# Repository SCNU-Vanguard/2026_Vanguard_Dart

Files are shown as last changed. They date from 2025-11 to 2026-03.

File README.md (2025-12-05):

# 2026 Vanguard Dart Project

## 项目简介 / Project Overview

本仓库为华南师范大学 Vanguard 战队 2026 赛季飞镖系统的综合仓库，包含 STM32 控制系统、视觉处理系统、飞镖系统机械结构和上位机图形化界面。

This repository contains the comprehensive codebase for SCNU Vanguard's 2026 season Dart system, including STM32 control system, vision processing system, dart's structure and upper computer GUI.

## 项目结构 / Project Structure

```
2026_Vanguard_Dart/
├── 2026_Vanguard_Dart_STM32_Ctrl/    # STM32控制系统 (C/C++)
│   ├── Dart_Ctrl/                     # STM32主控代码（A板）
│   └── 相关手册/                      # 相关技术文档
│
├── 2026_Vanguard_Dart_JestonPart/    # Jetson视觉处理系统 (Python/C++)
│   └── README.md                      # 视觉系统文档
│
└── 2026_Vanguard_Dart_UPC_Code/      # 上位机图形化界面 (Python)
|   ├── SourceCode/                    # 源代码
|   ├── docs/                          # 文档
|   ├── tests/                         # 测试代码
└── 2026_Vangaurd_Dart_Structure
    └──飞镖(V2improved)                #飞镖系统机械机构
```

## 功能模块 / Function Modules

### 1. STM32 控制系统 (STM32 Control System)

- **平台**: STM32F427xx（A 板）
- **开发环境**: Keil MDK-ARM
- **功能**:
  - 飞镖发射控制
  - CAN 总线通信
  - 电机控制 (大疆/达妙电机)
  - UART 通信
  - FreeRTOS 实时操作系统

### 2. 视觉处理系统 (Vision Processing System)

- **平台**: NVIDIA Jetson
- **功能**:
  - 目标识别与追踪
  - 图像处理
  - 视觉算法

### 3. 上位机系统 (Upper Computer System)

- **语言**: Python
- **功能**:
  - 实时数据监控
  - 参数调试界面
  - 数据可视化
  - UART 串口通信

## 开发环境 / Development Environment

### STM32 开发

- **IDE**: Keil MDK-ARM / STM32CubeIDE
- **调试器**: ST-Link
- **工具链**: ARM GCC

### 视觉处理

- **系统**: Ubuntu (Jetson)
- **语言**: Python 3.x / C++
- **依赖**: OpenCV, NumPy 等

### 上位机开发

- **语言**: Python 3.x
- **主要库**: PyQt5/PySide, pyserial, matplotlib 等
- **详见**: `2026_Vanguard_Dart_UPC_Code/requirements.txt`

## 快速开始 / Quick Start

### STM32 部分

```bash
cd 2026_Vanguard_Dart_STM32_Ctrl/Dart_Ctrl
# 使用Keil打开 Dart_Ctrl.uvprojx 工程文件
```

### 视觉处理部分

```bash
cd 2026_Vanguard_Dart_JestonPart
# 查看README.md了解详细说明
```

### 上位机部分

```bash
cd 2026_Vanguard_Dart_UPC_Code
# 安装依赖
pip install -r requirements.txt
# 运行主程序
python SourceCode/main_app.py
```

## 技术栈 / Tech Stack

- **嵌入式**: C/C++, FreeRTOS, STM32 HAL
- **视觉**: Python/C++, OpenCV
- **上位机**: Python, PyQt5, Matplotlib
- **通信**: UART, CAN
- **版本控制**: Git

## 贡献指南 / Contributing

1. Fork 本仓库
2. 创建特性分支 (`git checkout -b feature/AmazingFeature`)
3. 提交更改 (`git commit -m 'Add some AmazingFeature'`)
4. 推送到分支 (`git push origin feature/AmazingFeature`)
5. 提交 Pull Request

## 团队 / Team

华南师范大学 Vanguard 战队  
SCNU Vanguard Team

## 许可证 / License

本项目仅供华南师范大学 Vanguard 战队内部学习和比赛使用。

This project is for internal learning and competition use of SCNU Vanguard Team only.

---

_Last Updated: 2025 年 12 月_

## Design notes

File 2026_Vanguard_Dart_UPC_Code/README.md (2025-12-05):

# 上位机助手 (Host Computer Assistant)

**版本 v1.0.01 - UI 美化增强版**

---

## 📝 项目简介

本项目是一个基于 **Ubuntu 22.04** 和 **PyQt5** 开发的上位机助手，使用 **Python 3.10+**。专注于 **UART 串口通信**，支持 USB 虚拟串口和实体硬件串口（如 Jetson Nano 的/dev/ttyTHS1），用于与下位机（如 STM32、Arduino 等）进行通信、实时调节 PID 参数、多通道波形显示。

本项目原为华南师范大学 Vanguard 战队飞镖机器人上位机研发项目。

---

## ✨ 特性

### 核心功能

- **现代 UI 设计**: 采用黑色背景与粉色点缀的时尚界面风格
- **专注 UART 通信**: 精简的 UART 串口通信方案
  - 支持 USB 转 UART 虚拟串口（/dev/ttyUSB0, /dev/ttyACM0 等）
  - 支持实体 UART 硬件串口（Jetson Nano: /dev/ttyTHS1, Raspberry Pi: /dev/ttyAMA0 等）
  - **自动串口扫描和刷新** - 无需手动输入
- **模块化设计**: 通信功能封装在独立模块中，易于维护和扩展
- **实时 PID 调节**: 提供专门界面用于动态调整下位机的 PID 参数
- **手动控制**: 支持手动指令发送和 Hex 格式

### 🆕 v1.0.01 功能

- **智能日志系统**

  - 自动时间戳标记
  - 颜色分类显示（错误/成功/发送/接收）
  - 自动滚动到最新消息

- **多通道实时波形显示**

  - 支持同时显示多条曲线
  - 8 种预设颜色自动区分
  - 实时图例显示
  - 暂停/继续绘图控制
  - 自动缩放功能
  - 数据缓冲管理（默认 1000 点）

- **状态栏信息**

  - 实时连接状态显示
  - 数据接收统计
  - 绘图点数和通道数统计

- **配置持久化**

  - 自动保存上次使用的串口和波特率
  - 下次启动自动加载配置

- **数据导出**: 支持多通道波形数据导出为 CSV 格式

- **字体全面加粗**

  - 全局字体权重提升至 600 (Semi-Bold)
  - 所有文字更清晰醒目
  - 特别优化低 DPI 显示器显示效果

- **圆角美化**

  - 所有组件圆角增大 30-67%
  - 分组框: 10px → 15px
  - 输入框/按钮: 5px → 8px
  - 标签页: 8px → 10px
  - 主窗口: 0px → 12px

- **边框增强**

  - 所有边框加粗至 2px (原来 1px)
  - 组件边界更清晰
  - 视觉层次更分明

- **内边距优化**

  - 所有组件内边距增加 20-50%
  - 界面更宽松，呼吸感更好
  - 分组框增加 15px padding

- **新增样式**

  - 工具按钮圆角和悬停效果
  - 分组框标题增加背景和圆角
  - 复选框尺寸增大 20%
  - 滚动条加粗更易拖动

- **代码规范**: 遵循 PEP8 代码规范，确保代码高质量和可读性

---

## 🛠️ 环境要求

### 系统要求

- **操作系统**: Ubuntu 22.04 LTS（推荐）或其他 Linux 发行版
- **Python 版本**: Python 3.10 或更高
- **硬件**: 支持 USB 串口或板载硬件串口（如 Jetson Nano）

### 依赖包

- PyQt5 >= 5.15.0
- pyserial >= 3.5

---

## 📦 安装方法

### 方法一：使用 Miniconda 虚拟环境（推荐）

#### 1. 安装 Miniconda

如果还没有安装 Miniconda，请先安装：

```bash
# 下载Miniconda安装脚本
wget https://repo.anaconda.com/miniconda/Miniconda3-latest-Linux-x86_64.sh

# 运行安装脚本
bash Miniconda3-latest-Linux-x86_64.sh

# 按照提示完成安装，重启终端使其生效
```

#### 2. 创建并激活虚拟环境

```bash
# 创建名为uart_host的Python 3.10环境
conda create -n uart_host python=3.10 -y

# 激活环境
conda activate uart_host
```

#### 3. 安装依赖

```bash
# 进入项目目录
cd /path/to/LinuxUPC

# 安装系统依赖（仅首次需要）
sudo apt update
sudo apt install -y build-essential

# 使用Conda安装PyQt5
conda install -y pyqt

# 安装其他Python依赖
pip install -r requirements.txt
```

#### 4. 配置串口权限

```bash
# 将当前用户添加到dialout组（仅首次需要）
sudo usermod -a -G dialout $USER

# ⚠️ 需要重新登录或重启才能生效
```

#### 5. 运行程序

```bash
# 确保在uart_host环境中
conda activate uart_host

# 运行主程序
python SourceCode/main_app.py
```

---

### 方法二：系统级安装

#### 1. 更新系统包

```bash
sudo apt update && sudo apt upgrade -y
```

#### 2. 安装 Python 和系统依赖

```bash
# 确认Python版本
python3 --version

# 安装依赖
sudo apt install -y python3 python3-pip build-essential
sudo apt install -y python3-pyqt5 python3-pyqt5.qtsvg
```

#### 3. 安装 Python 包

```bash
pip3 install -r requirements.txt
```

#### 4. 配置串口权限

```bash
sudo usermod -a -G dialout $USER
# ⚠️ 需要重新登录或重启
```

#### 5. 运行程序

```bash
python3 SourceCode/main_app.py
```

---

### 方法三：使用自动化脚本

```bash
# 赋予执行权限
chmod +x setup_environment.sh

# 运行配置脚本（自动检测Conda环境）
./setup_environment.sh
```

---

## 🚀 快速开始

### 1. 识别串口设备

```bash
# 列出所有串口设备
ls /dev/tty*

# 查看USB串口（插拔USB观察变化）
ls /dev/ttyUSB*
ls /dev/ttyACM*

# Jetson Nano硬件串口
ls /dev/ttyTHS*
```

### 2. 测试串口连接

```bash
# 查看串口权限
ls -l /dev/ttyUSB0

# 应该看到类似：crw-rw---- 1 root dialout ...
# 确保你的用户在dialout组中
groups
```

### 3. 启动程序

```bash
# 使用Conda环境
conda activate uart_host
python SourceCode/main_app.py

# 或系统Python
python3 SourceCode/main_app.py
```

### 4. 连接设备

1. 在"UART 通信设置"区域输入串口端口（或使用快速选择按钮）
2. 选择波特率（默认 115200）
3. 点击"连接"按钮
4. 在日志区域查看连接状态

---

## 📂 项目结构

```
LinuxUPC/
├── SourceCode/
│   ├── main_app.py              # 主程序入口
│   └── communication/           # 通信模块
│       ├── __init__.py          # 模块初始化
│       └── uart_comm.py         # UART通信实现
├── Weekly/                      # 开发周报
├── requirements.txt             # Python依赖列表
├── setup_environment.sh         # 自动配置脚本
├── README.md                    # 本文件
└── LICENSE                      # 开源协议
```

---

## 🔧 通信协议

### PID 参数发送格式

```
PID,<Kp>,<Ki>,<Kd>
示例: PID,1.0000,0.1000,0.0100
```

### 手动控制指令格式

```
<COMMAND>,<PARAM1>,<PARAM2>,...
示例: MOTOR,1,255
```

### 绘图数据接收格式

```
AT+DRAW+<数据名称>+<数值>
示例:
  AT+DRAW+Temperature+25.5
  AT+DRAW+Voltage+3.3
  AT+DRAW+Humidity+65.2
```

详细绘图功能说明请参考：[docs/绘图功能说明.md](docs/绘图功能说明.md)

---

## 🎨 UI 优化

### 1. 串口管理

- 🔄 **自动扫描**: 启动时自动检测可用串口
- 🔍 **智能显示**: 显示串口设备名称和描述
- ⚡ **快速选择**: USB0/THS1/ACM0 快捷按钮

### 2. 日志增强

- ⏰ **时间戳**: 每条日志自动添加时间（HH:MM:SS 格式）
- 🎨 **颜色编码**:
  - 🔴 红色：错误和失败
  - 🟢 绿色：成功和连接
  - 🔵 蓝色：绘图数据
  - 🟡 黄色：发送命令
  - ⚪ 灰色：一般信息

### 3. 波形控制

- ⏸/▶ **暂停/继续**: 暂停数据绘制但保持接收
- 📐 **自动缩放**: 一键调整视图适应所有数据
- 🗑 **清空波形**: 清除所有曲线和数据
- 💾 **导出数据**: CSV 格式导出所有通道

### 4. 状态栏

- 📊 **实时统计**:
  - 连接状态和串口信息
  - 接收数据包总数
  - 绘图点总数
  - 活动通道数量

---

## 🎯 常见问题

### 1. 串口权限问题

**错误**: `Permission denied: '/dev/ttyUSB0'`

**解决**:

```bash
sudo usermod -a -G dialout $USER
# 重新登录或重启
```

### 2. 串口被占用

**错误**: `Serial port is already open`

**解决**:

```bash
# 查找占用进程
lsof /dev/ttyUSB0

# 结束占用进程
kill -9 <PID>
```

### 3. Jetson Nano 串口配置

对于 Jetson Nano 的硬件串口/dev/ttyTHS1，需要禁用控制台：

```bash
# 禁用串口控制台
sudo systemctl stop nvgetty
sudo systemctl disable nvgetty
```

### 4. PyQt5 安装问题

如果使用 pip 安装 PyQt5 失败，建议：

**Conda 环境**:

```bash
conda install -y pyqt
```

**系统环境**:

```bash
sudo apt install python3-pyqt5
```

---

## 🤝 贡献

欢迎提交 Issue 和 Pull Request！

---

## 📄 开源协议

本项目采用 MIT License，详见 [LICENSE](LICENSE) 文件。

---

## 👨‍💻 作者

**BaleDeng** - 华南师范大学 Vanguard 战队

项目开发日期: 2025-09

当前版本: v1.0.01

---

## 📋 更新日志

### v1.0.00 (2025-09-20) -> v1.0/01 (2025-11-18) - UART 专版

- 🎨 全局字体加粗至 600 (Semi-Bold)
- 🎨 所有圆角增大 30-67%
- 🎨 所有边框加粗至 2px
- 🎨 所有内边距增加 20-50%
- 🎨 新增工具按钮样式
- 🎨 分组框标题增加背景和圆角
- 🎨 复选框尺寸增大 20%
- 🎨 滚动条加粗更易拖动
- 📝 新增 UI 美化对比文档

- ✨ 新增自动串口扫描和刷新功能
- ✨ 新增带时间戳和颜色的智能日志系统
- ✨ 新增实时状态栏和统计信息
- ✨ 新增配置文件自动保存/加载
- ✨ 新增多通道波形显示功能
- ✨ 新增绘图暂停/继续控制
- ✨ 新增自动缩放功能
- 🎨 优化 UI 布局和窗口大小
- 🐛 修复断开连接时的潜在 bug
- 📝 完善文档和测试工具

- 🎉 初始版本发布
- ✨ UART 串口通信基础功能
- ✨ PID 参数调节
- ✨ 手动控制指令发送

---

## 📮 联系方式

如有问题或建议，请通过 GitHub Issues 联系。

---

# 飞镖上位机技术展望与开发方案

## 项目背景

基于当前战队采用拉簧式发射结构+无控飞镖，上位机与视觉暂未合体情况下，参考下面的开源工程以及报告总结。

目标功能：
- 具备场上参数修正功能
- 使用基于树莓派 5/香橙派 5Plus/Jetson Nano 等的可视化 GUI 进行调节 PID 等参数（测试情况下）
- 模拟比赛调节参数过程（梯度飞镖）
- 使用多次校准，从而确定随机固定靶的位置

---

## 飞镖相关开源项目参考

### 西北工业大学报告 (WMJ)

**链接**: <https://bbs.robomaster.com/article/809863?source=4>

**硬件部分**:
- 采用树莓派 Zero2W 平台
- 运行 RaspberryOS
- 使用 OpenCV 进行图像识别和处理
- 通过 CSI 相机数据流识别引导灯
- 串口通信基于 wiringpi 库，使用 CRC16 校验

**下位机**:
- STM32 使用 HAL 库裸机开发
- 板载 BMI088 + IST8310
- 采用 Mahony 算法进行四元数解算融合九轴 IMU

**镖架上位机**:
- 基于 Intel NUC10 平台（Ubuntu 20.04）
- 使用 OpenCV + GalaxyAPI（大恒工业相机）
- CAN 通信

---

### 四川大学 火锅战队 - 全站仪上位机开源

**链接**: 
- <https://bbs.robomaster.com/article/803749?source=4>
- <https://github.com/KangweiYang/dartRack_upper>

**技术方案**:
- 使用全站仪
- 软件以 Qt (C++) 为基础
- 集成串口界面进行标定数据通信
- 通过串口调节界面调节参数

---

### 西安交通大学 笃行战队

**链接**: <https://bbs.robomaster.com/article/803714?source=4>

**特点**:
- 基于皮筋发射系统
- 未开源上位机实现方案

---

### 西南大学 GKD 战队 (RM2021)

**链接**: 
- <https://bbs.robomaster.com/article/8355>
- <https://gitee.com/gong-yuzhi/rmfashejia> - 发射架结构
- <https://gitee.com/rogue_shadowdancer/gkdfeibiao> - 飞镖结构

**技术方案**:
- 皮筋发射结构
- 使用 nRF24L01 模块作为远程调参接收的载体
- 上位机采用 PyQt5 设计
- 理论最远 10 米进行调参
- 使用第三方串口软件（类似 VOFA、SerialPlot）进行可视化监控
- 支持波形导出为 .csv 文件，便于 Excel/Matlab 分析

---

### 西南交通大学 Helios 战队 - 制导飞镖

**链接**: 
- <https://bbs.robomaster.com/article/715957?source=4>
- <https://github.com/kid-king-x/DartGuide2025-Helios>

**技术方案**:
- RV1126 作为上位机
- 未提及上位机 GUI 方案

---

### 华南理工大学 华南虎 (RM2023)

**链接**: <https://bbs.robomaster.com/article/xxx>

**技术方案**:
- 使用 ESP32 与 STM32 系列控制板进行通信
- 基于 ESP32 开发上位机 HMI（人机界面）
- 应该使用 LVGL 实现
- 离线调参功能

---

### 大连理工大学 凌 Bug (2024)

**技术方案**:
- 上位机基于 Node.js 和 Electron
- 使用 JavaScript, HTML 和 CSS 编写
- 实现功能：
  - 机器人调试
  - 通信协议管理
  - 代码工程管理
- 通讯数据可视化，绘制成曲线或保存在本地
- 有控飞镖的视觉部分交由 STM32H7 系列主控实现

**机械要求**:
- 需要机械提供精准参数
- 拉簧选型
- 飞镖细节问题调整：
  - 飞镖内部重量分配
  - 缓冲位置精确控制
  - 滑台震动控制
  - 无控飞镖精确度与一致性
  - 不同场地不同方位时的飞镖校准

---

### 南航 (2022)

**技术方案**:
- 未使用上位机（无控飞镖）

---

## 飞镖上位机方案实现

### 核心需求

对于飞镖上位机，现在的要求非常明确：

1. **最紧迫需求**：打通视觉与下位机的通讯
2. **硬件平台**：Jetson 系列作为当前主控（性能最强劲方案）
3. **功能要求**：
   - 保证飞镖的瞄准
   - 处理视觉数据并解算发送给下位机
   - 下位机电控数据、参数上传上位机
   - 提供反馈曲线，方便调试人员数据调试总结

### 技术方案选型

目前尝试了两个方向：

#### 方案一：基于 C/C++ 的 LVGL 库

**优点**:
- CPU 资源占用较低
- 固定单核运行执行文件

**缺点**:
- 代码繁琐
- 使用 SquareLine Studio 开发（收费，可白嫖 30 天）

---

#### 方案二：基于 C++/Python 的 Qt 库（当前采用）

**优点**:
- 使用更便捷的 PyQt5/6 开发
- Qt Designer 免费
- 大部分开源工程选择 Qt
- 便于后期维护

**缺点**:
- 多核调度
- 资源占用稍高（但与 LVGL 差不多）

**决策**:
为了后期维护以及参考大部分开源工程，当前采用 Qt 进行开发。

---

### 开发进展

**已完成**:
- ✅ Qt 开发环境配置和编写
- ✅ 基础 UI 界面设计
- ✅ UART 串口通信模块
- ✅ PID 参数调节界面
- ✅ 实时波形显示功能
- ✅ 数据导出功能

**待完成**:
- ⏳ 多线程部分（需为视觉接口预留）
- ⏳ 各种数据流输入接口确定
- ⏳ 回调函数优化
- ⏳ 信号与槽的处理完善
- ⏳ 与下位机通信测试
- ⏳ 与视觉的数据对接

---

### 通信方案

下位机通信协议可选方案：
- ✅ UART 串口通信（当前采用）
- ⏳ CAN 通信
- ⏳ RS485 通信
- ⏳ I2C 通信

目前还未完全测试与下位机通信，可以先测试各种通信方式。

**视觉方面**：
- 仍然待定，需要继续与视觉进行沟通
- 需确定视觉数据包格式

---

## 总结

上位机的 GUI 以及通信部分都亟待处理与沟通：

1. **GUI 需求**：
   - 不仅仅是参数调节的加减
   - 需要反馈曲线显示
   - 需要数据记录和导出

2. **通信需求**：
   - 调用对应库进行编写逻辑嵌入上位机即可
   - 需要明确通信协议
   - 需要与视觉、下位机进行联调

3. **未来方向**：
   - 当前方案仍建议为无控飞镖
   - 为后续有控飞镖做技术基础方面的参照
   - 基于技术问题，循序渐进

---

**文档创建时间**: 2025-09-21  
**最后更新**: 2025-12-05  
**维护者**: BaleDeng & Vanguard Team

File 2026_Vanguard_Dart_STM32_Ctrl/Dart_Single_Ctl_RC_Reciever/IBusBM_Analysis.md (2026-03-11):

# IBusBM 库代码分析文档

## 1. 项目概述

IBusBM 是一个用于处理 Flysky/Turnigy RC iBUS 协议的 Arduino 库，主要用于与 **IA6B** 等接收机通信。

### 1.1 支持的功能
- **接收伺服通道数据**：从接收机读取最多14个通道的控制信号
- **传感器/遥测数据发送**：将传感器数据（电压、温度、转速等）回传至发射机
- **多平台支持**：AVR、ESP32、STM32、MBED、MegaAVR

### 1.2 硬件接口
- TGY-IA6B 接收机有两个 iBUS 引脚：
  - **伺服输出引脚**：仅输出伺服控制数据
  - **传感器引脚**：使用半双工协议进行双向通信

---

## 2. iBUS 协议详解

### 2.1 协议特性
- **波特率**：115200
- **数据格式**：8N1 (8位数据，无校验，1位停止位)
- **数据包发送频率**：约每 7ms 一次
- **半双工**：传感器通道使用单线半双工通信

### 2.2 数据包结构

#### 伺服命令包 (0x40)
```
长度: 32 字节 (0x20)
格式: <len><cmd><ch0_L><ch0_H><ch1_L><ch1_H>...<ch13_L><ch13_H><chkL><chkH>
```

**示例数据包**：
```
20 40 DB 05 DC 05 54 05 DC 05 E8 03 D0 07 D2 05 E8 03 DC 05 DC 05 DC 05 DC 05 DC 05 DC 05 DA F3
```

**解析**：
| 字节 | 值 | 说明 |
|---|---|---|
| 0x20 | 32 | 协议长度 |
| 0x40 | 64 | 命令码（伺服命令） |
| 0x05DB | 1499 | 通道0值 |
| 0x05DC | 1500 | 通道1值 |
| ... | ... | ... |
| 0xF3DA | 校验和 | 所有前面字节相加后取反 |

#### 传感器协议命令
| 命令 | 值 | 说明 |
|---|---|---|
| DISCOVER | 0x80 + addr | 发现传感器 |
| TYPE | 0x90 + addr | 查询传感器类型 |
| VALUE | 0xA0 + addr | 请求传感器数据 |

### 2.3 校验和计算
```
checksum = 0xFFFF - (所有前面字节之和)
```

### 2.4 通道值范围
- **最小值**：1000 (0x03E8) - 油门最低/摇杆最左
- **中立值**：1500 (0x05DC)
- **最大值**：2000 (0x07D0) - 油门最高/摇杆最右

---

## 3. 核心数据结构

### 3.1 IBusBM 类定义 (`src/IBusBM.h`)

```cpp
class IBusBM {
public:
  // STM32专用begin函数
  void begin(HardwareSerial &serial, TIM_TypeDef * timerid=TIM1, 
             int8_t rxPin=-1, int8_t txPin=-1);
  
  // 通用begin函数
  void begin(HardwareSerial &serial, int8_t timerid=0, 
             int8_t rxPin=-1, int8_t txPin=-1);
  
  uint16_t readChannel(uint8_t channelNr);      // 读取伺服通道 0-13
  uint8_t addSensor(uint8_t type, uint8_t len=2); // 添加传感器
  void setSensorMeasurement(uint8_t adr, int32_t value); // 设置传感器值
  void loop(void);  // 主循环处理函数

  // 统计计数器
  volatile uint8_t cnt_poll;   // 传感器轮询消息计数
  volatile uint8_t cnt_sensor; // 传感器数据发送计数
  volatile uint8_t cnt_rec;    // 伺服消息接收计数

private:
  // 状态机状态
  enum State {GET_LENGTH, GET_DATA, GET_CHKSUML, GET_CHKSUMH, DISCARD};
  
  // 协议常量
  static const uint8_t PROTOCOL_LENGTH = 0x20;      // 数据包最大长度
  static const uint8_t PROTOCOL_OVERHEAD = 3;       // 开销字节数
  static const uint8_t PROTOCOL_TIMEGAP = 3;        // 数据包间隔时间(ms)
  static const uint8_t PROTOCOL_CHANNELS = 14;      // 最大通道数
  static const uint8_t SENSORMAX = 10;              // 最大传感器数
  
  // 协议命令
  static const uint8_t PROTOCOL_COMMAND40 = 0x40;         // 伺服命令
  static const uint8_t PROTOCOL_COMMAND_DISCOVER = 0x80;  // 发现传感器
  static const uint8_t PROTOCOL_COMMAND_TYPE = 0x90;      // 查询传感器类型
  static const uint8_t PROTOCOL_COMMAND_VALUE = 0xA0;     // 请求传感器数据
  
  // 成员变量
  uint8_t state;                       // 状态机当前状态
  HardwareSerial *stream;              // 串口指针
  uint32_t last;                       // 上次消息时间戳
  uint8_t buffer[PROTOCOL_LENGTH];     // 消息缓冲区
  uint8_t ptr;                         // 缓冲区指针
  uint8_t len;                         // 当前消息长度
  uint16_t channel[PROTOCOL_CHANNELS]; // 伺服通道数据
  uint16_t chksum;                     // 校验和
  
  // 传感器信息结构
  typedef struct {
    uint8_t sensorType;      // 传感器类型
    uint8_t sensorLength;    // 数据长度 (2或4字节)
    int32_t sensorValue;     // 传感器值
  } sensorinfo;
  sensorinfo sensors[SENSORMAX];
};
```

### 3.2 传感器类型定义

```cpp
#define IBUSS_INTV 0x00  // 内部电压 (单位: 0.01V)
#define IBUSS_TEMP 0x01  // 温度 (单位: 0.1°C, 0=-40°C)
#define IBUSS_RPM  0x02  // 转速 (RPM)
#define IBUSS_EXTV 0x03  // 外部电压 (单位: 0.01V)
#define IBUS_PRESS 0x41  // 压力 (Pa)
#define IBUS_SERVO 0xfd  // 伺服值
```

---

## 4. 状态机与数据接收流程

### 4.1 状态机工作流程

```
      ┌─────────────┐
      │   DISCARD   │◄────────────────────────────┐
      └──────┬──────┘                              │
             │ (超时 >= 3ms)                        │
             ▼                                      │
      ┌─────────────┐                              │
      │ GET_LENGTH  │                              │
      └──────┬──────┘                              │
             │ (len有效: 4-32)                      │
             ▼                                      │
      ┌─────────────┐                              │
      │  GET_DATA   │                              │
      └──────┬──────┘                              │
             │ (数据接收完成)                       │
             ▼                                      │
      ┌─────────────┐                              │
      │ GET_CHKSUML │                              │
      └──────┬──────┘                              │
             │                                      │
             ▼                                      │
      ┌─────────────┐      校验成功                │
      │ GET_CHKSUMH │──────────────► 处理命令 ─────┤
      └─────────────┘      校验失败                │
                           ─────────────────────────┘
```

### 4.2 loop() 函数核心逻辑

```cpp
void IBusBM::loop(void) {
  // 递归调用链表中的下一个实例
  if (IBusBMnext) IBusBMnext->loop(); 

  while (stream->available() > 0) {
    // 检测时间间隔，超过3ms认为是新数据包开始
    uint32_t now = millis();
    if (now - last >= PROTOCOL_TIMEGAP) {
      state = GET_LENGTH;
    }
    last = now;
    
    uint8_t v = stream->read();
    
    switch (state) {
      case GET_LENGTH:
        // 验证长度字段有效性 (4-32字节)
        if (v <= PROTOCOL_LENGTH && v > PROTOCOL_OVERHEAD) {
          ptr = 0;
          len = v - PROTOCOL_OVERHEAD;  // 实际数据长度
          chksum = 0xFFFF - v;          // 初始化校验和
          state = GET_DATA;
        } else {
          state = DISCARD;
        }
        break;

      case GET_DATA:
        buffer[ptr++] = v;
        chksum -= v;
        if (ptr == len) {
          state = GET_CHKSUML;
        }
        break;
        
      case GET_CHKSUML:
        lchksum = v;
        state = GET_CHKSUMH;
        break;

      case GET_CHKSUMH:
        // 校验和验证
        if (chksum == (v << 8) + lchksum) {
          // 处理有效命令
          processCommand();
        }
        state = DISCARD;
        break;
    }
  }
}
```

### 4.3 命令处理

#### 伺服命令 (0x40)
```cpp
if (buffer[0] == PROTOCOL_COMMAND40) {
  // 提取14个通道的数据 (小端序)
  for (uint8_t i = 1; i < PROTOCOL_CHANNELS * 2 + 1; i += 2) {
    channel[i / 2] = buffer[i] | (buffer[i + 1] << 8);
  }
  cnt_rec++;  // 增加接收计数
}
```

#### 传感器命令处理
```cpp
// DISCOVER命令 (0x80): 发现传感器
// 响应: 0x04, 0x81+addr, checksum_L, checksum_H

// TYPE命令 (0x90): 查询传感器类型
// 响应: 0x06, 0x91+addr, type, length, checksum_L, checksum_H

// VALUE命令 (0xA0): 请求传感器数据
// 响应: 0x04+len, 0xA1+addr, value_bytes..., checksum_L, checksum_H
```

---

## 5. STM32 特定实现

### 5.1 平台检测与定时器配置

STM32 使用 HardwareTimer 库实现定时中断：

```cpp
#if defined(_VARIANT_ARDUINO_STM32_)
  #if !defined(STM32_CORE_VERSION) || (STM32_CORE_VERSION < 0x01090000)
    #error "Due to API change, this sketch is compatible with STM32_CORE_VERSION >= 0x01090000"
  #endif
  #define IBUSBM_NOTIMER NULL  // STM32使用NULL表示禁用定时器
  void begin(HardwareSerial &serial, TIM_TypeDef * timerid=TIM1, 
             int8_t rxPin=-1, int8_t txPin=-1);
#endif
```

### 5.2 STM32 定时器初始化

```cpp
#elif defined(_VARIANT_ARDUINO_STM32_)
  // 使用STM32 HardwareTimer库
  // 参考: https://github.com/stm32duino/wiki/wiki/HardwareTimer-library
  HardwareTimer *stimer_t = new HardwareTimer(timerid);
  stimer_t->setOverflow(1000, HERTZ_FORMAT);  // 1000 Hz (1ms周期)
  stimer_t->attachInterrupt(onTimer);          // 绑定中断回调
  stimer_t->resume();                          // 启动定时器
```

### 5.3 STM32 使用示例 (Ibus_diy_servo_STM32)

```cpp
// 关键配置
#include <IBusBM.h>
#include <PID_v1.h>

IBusBM IBUS;

void setup() {
  // 在Serial1上启动IBus，禁用内部定时器
  // STM32F103C8T6 (Blue Pill): PA10 = RX1
  IBUS.begin(Serial1, IBUSBM_NOTIMER);
  
  // 等待接收机连接
  while (IBUS.cnt_rec == 0) {
    IBUS.loop();
    delay(1);
  }
}

void loop() {
  // 创建1ms循环
  if (CurrentMillis != millis()) {
    IBUS.loop();  // 手动调用loop处理IBus数据
    MillisCount++;
    CurrentMillis = millis();
    
    if (MillisCount > 7) {  // 每8ms处理一次 (125Hz)
      // 读取通道数据
      int STEER = IBUS.readChannel(STEER_chan - 1);
      
      // 检测连接状态
      if (IBUS.cnt_rec == IbusCount) {
        // 无新数据 - 失联保护
        disableMotor();
      } else {
        // 正常处理伺服控制
        processServo();
      }
      
      IbusCount = IBUS.cnt_rec;
      MillisCount = 0;
    }
  }
}
```

### 5.4 STM32 引脚配置

| 型号 | 串口 | RX引脚 | TX引脚 | 说明 |
|---|---|---|---|---|
| STM32F103C8T6 | Serial1 | PA10 | PA9 | Blue Pill |
| STM32F103C8T6 | Serial2 | PA3 | PA2 | Blue Pill |
| STM32F103C8T6 | Serial3 | PB11 | PB10 | Blue Pill |

### 5.5 STM32 注意事项

1. **核心版本要求**：需要 `STM32_CORE_VERSION >= 0x01090000`
2. **默认定时器**：TIM1，如果TIM1被其他功能占用（如Servo或SoftwareSerial），需要更换
3. **NOTIMER模式**：使用 `IBUSBM_NOTIMER` (NULL) 禁用内部定时器，需手动调用 `loop()`
4. **串口波特率**：固定115200，无需手动配置

---

## 6. 接收机数据处理流程图

```
┌──────────────────────────────────────────────────────────────────┐
│                      IA6B 接收机                                  │
│  ┌────────────────┐    ┌────────────────┐                        │
│  │  伺服输出引脚   │    │  传感器引脚    │                        │
│  │ (单向输出)      │    │ (半双工)       │                        │
│  └───────┬────────┘    └───────┬────────┘                        │
└──────────┼─────────────────────┼────────────────────────────────┘
           │                     │
           │ (RX)                │ (RX + TX)
           │                     │ (需要二极管或1.2k电阻)
           ▼                     ▼
┌──────────────────────────────────────────────────────────────────┐
│                       STM32 / Arduino                             │
│                                                                   │
│   ┌─────────────────────────────────────────────────────────┐    │
│   │                    IBusBM 库                             │    │
│   │                                                          │    │
│   │  ┌──────────┐    ┌──────────────┐    ┌──────────────┐   │    │
│   │  │ 定时器   │───►│  loop()函数  │───►│ 状态机解析   │   │    │
│   │  │ (1ms)    │    │              │    │              │   │    │
│   │  └──────────┘    └──────────────┘    └──────┬───────┘   │    │
│   │                                              │           │    │
│   │                         ┌────────────────────┼───────┐   │    │
│   │                         │                    │       │   │    │
│   │                         ▼                    ▼       │   │    │
│   │               ┌──────────────┐    ┌──────────────┐   │   │    │
│   │               │ channel[14]  │    │ 传感器响应   │   │   │    │
│   │               │ 伺服通道数据 │    │              │   │   │    │
│   │               └──────┬───────┘    └──────────────┘   │   │    │
│   │                      │                               │   │    │
│   └──────────────────────┼───────────────────────────────┘   │    │
│                          │                                    │    │
│                          ▼                                    │    │
│   ┌──────────────────────────────────────────────────────────┐    │
│   │                    用户应用代码                           │    │
│   │                                                          │    │
│   │  readChannel(n)  ───► 获取通道值 (1000-2000)             │    │
│   │  addSensor()     ───► 添加传感器                         │    │
│   │  setSensorMeasurement() ───► 设置传感器数据              │    │
│   │                                                          │    │
│   └──────────────────────────────────────────────────────────┘    │
│                                                                   │
└───────────────────────────────────────────────────────────────────┘
```

---

## 7. API 接口总结

### 7.1 初始化函数

```cpp
// STM32版本
void begin(HardwareSerial &serial, 
           TIM_TypeDef * timerid = TIM1,    // 定时器，NULL禁用
           int8_t rxPin = -1,                // 默认使用串口默认引脚
           int8_t txPin = -1);

// 其他平台版本  
void begin(HardwareSerial &serial,
           int8_t timerid = 0,              // 定时器ID，-1禁用
           int8_t rxPin = -1,
           int8_t txPin = -1);
```

### 7.2 通道读取

```cpp
uint16_t readChannel(uint8_t channelNr);
// 参数: channelNr = 0-13 (对应遥控器通道1-14)
// 返回: 1000-2000 (对应PWM微秒值)
```

### 7.3 传感器操作

```cpp
uint8_t addSensor(uint8_t type, uint8_t len = 2);
// 参数: type = 传感器类型, len = 数据长度(2或4字节)
// 返回: 传感器地址 (1开始)

void setSensorMeasurement(uint8_t adr, int32_t value);
// 参数: adr = 传感器地址, value = 传感器值
```

### 7.4 状态计数器

```cpp
volatile uint8_t cnt_rec;    // 伺服消息接收计数 (用于连接检测)
volatile uint8_t cnt_poll;   // 传感器轮询计数
volatile uint8_t cnt_sensor; // 传感器响应计数
```

---

## 8. 故障安全 (Failsafe)

### 8.1 连接检测方法

```cpp
static uint8_t lastCnt = 0;

void loop() {
  IBUS.loop();
  
  // 检查cnt_rec是否更新
  if (IBUS.cnt_rec == lastCnt) {
    // 超过一定时间无更新 = 可能失联
    activateFailsafe();
  } else {
    // 正常接收数据
    lastCnt = IBUS.cnt_rec;
    processControl();
  }
}
```

### 8.2 注意事项

> **重要**：`cnt_rec` 不能直接用于失联检测，因为支持遥测的接收机即使与发射机断连也会继续发送伺服数据。
> 
> 建议方案：
> - 非遥测接收机 (如 FS-A8S V2)：可使用 `cnt_rec` 检测
> - 遥测接收机 (如 X6B)：在发射机端设置某个通道的失联值，通过 `readChannel()` 检测

---

## 9. 编译与使用

### 9.1 STM32 编译环境
- Arduino IDE + STM32 核心库 (版本 >= 1.9.0)
- PlatformIO + stm32duino

### 9.2 基本使用流程

```cpp
#include <IBusBM.h>

IBusBM ibus;

void setup() {
  // 初始化串口和IBus
  ibus.begin(Serial1);  // 使用Serial1，启用定时器中断
}

void loop() {
  // 读取通道值
  uint16_t ch1 = ibus.readChannel(0);  // 通道1
  uint16_t ch2 = ibus.readChannel(1);  // 通道2
  
  // 处理控制逻辑
  // ...
}
```

---

## 10. 总结

IBusBM 库通过状态机实现了对 iBUS 协议的完整解析，支持：

1. **多平台兼容**：AVR、ESP32、STM32、MBED 架构
2. **双向通信**：接收伺服数据 + 发送传感器数据
3. **中断驱动**：使用定时器中断确保实时响应
4. **灵活配置**：支持禁用定时器手动调用 loop()

对于 STM32 用户，关键点是：
- 使用 `TIM_TypeDef*` 类型指定定时器
- 默认使用 TIM1，如有冲突需更换
- 支持 IBUSBM_NOTIMER 模式手动调用
- 需要 STM32 核心库版本 >= 1.9.0

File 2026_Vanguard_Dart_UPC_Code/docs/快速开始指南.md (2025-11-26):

# 上位机助手 v3.1 快速开始指南

## 🚀 5分钟上手指南

### 第一步：安装依赖

```bash
cd /home/bale/QT/LinuxUPC

# 如果使用 Conda
conda activate uart_host
pip install -r requirements.txt

# 如果使用系统 Python
pip3 install -r requirements.txt
```

### 第二步：运行测试脚本

```bash
./test_features.sh
```

测试脚本会自动检查：
- ✓ Python 依赖是否安装
- ✓ 代码语法是否正确
- ✓ 串口权限是否配置
- ✓ 可用串口设备

### 第三步：启动程序

```bash
cd SourceCode
python3 main_app.py
```

---

## 🎯 新功能体验指南

### 1. 串口自动扫描 (30秒)

**操作步骤**:
1. 启动程序后，观察"串口端口"下拉框
2. 应该能看到系统中所有可用的串口设备
3. 点击🔄刷新按钮，列表会重新扫描

**预期效果**:
```
/dev/ttyUSB0 - USB-Serial Controller
/dev/ttyACM0 - Arduino Uno
/dev/ttyTHS1 - Tegra UART
```

**快捷操作**:
- 点击"USB0"按钮 → 自动填入 `/dev/ttyUSB0`
- 点击"THS1"按钮 → 自动填入 `/dev/ttyTHS1`
- 点击"ACM0"按钮 → 自动填入 `/dev/ttyACM0`

---

### 2. 智能日志系统 (30秒)

**操作步骤**:
1. 连接串口设备
2. 观察日志窗口的变化

**预期效果**:
- 每条日志前有时间戳：`[14:23:15]`
- 不同类型的消息有不同颜色：
  - 成功消息显示为绿色
  - 错误消息显示为红色
  - 发送命令显示为黄色
  - 绘图数据显示为蓝色

**示例**:
```
[14:23:15] 已扫描到 3 个串口设备 (灰色)
[14:23:20] [UART] 连接成功 - /dev/ttyUSB0 @ 115200 (绿色)
[14:23:25] 发送: PID,1.0,0.1,0.01 (黄色)
[14:23:30] AT+DRAW+Temperature+25.5 (蓝色)
```

---

### 3. 实时状态栏 (1分钟)

**操作步骤**:
1. 连接串口
2. 发送一些绘图数据
3. 观察窗口底部的状态栏

**预期效果**:

左侧（连接状态）:
```
未连接              → 连接前
已连接: /dev/ttyUSB0 @ 115200  → 连接后
```

右侧（统计信息）:
```
接收: 0 | 绘图点: 0 | 通道: 0     → 初始状态
接收: 15 | 绘图点: 45 | 通道: 3   → 接收数据后
```

**更新频率**: 每秒自动更新

---

### 4. 波形显示控制 (2分钟)

#### 4.1 暂停/继续绘图

**操作步骤**:
1. 切换到"波形显示"标签页
2. 等待波形开始显示
3. 点击"⏸ 暂停绘图"按钮
4. 观察：波形停止更新，但数据仍在接收（状态栏数字继续增加）
5. 点击"▶ 继续绘图"按钮
6. 波形恢复更新

**使用场景**:
- 想仔细查看某段波形细节
- 数据更新太快，想暂停观察
- 截图或演示时冻结画面

#### 4.2 自动缩放

**操作步骤**:
1. 手动拖动或缩放波形图
2. 点击"📐 自动缩放"按钮
3. 视图自动调整以显示所有数据

**使用场景**:
- 数据范围变化大，手动调整麻烦
- 想快速查看全局数据

#### 4.3 清空波形

**操作步骤**:
1. 点击"🗑 清空波形"按钮
2. 所有曲线和数据被清除
3. 可以重新开始绘图

#### 4.4 导出数据

**操作步骤**:
1. 点击"💾 导出数据"按钮
2. 选择保存位置
3. 数据保存为CSV格式

**导出格式**:
```csv
Sample_Index,Current,Temperature,Voltage
0,0.5,25.1,3.3
1,0.6,25.3,3.29
2,0.7,25.5,3.31
```

---

### 5. 配置持久化 (30秒)

**操作步骤**:
1. 首次启动程序
2. 选择串口：`/dev/ttyUSB0`
3. 选择波特率：`115200`
4. 连接成功
5. 关闭程序
6. 重新启动程序

**预期效果**:
- 串口自动填充为 `/dev/ttyUSB0`
- 波特率自动填充为 `115200`

**配置文件位置**:
```
~/.config/uart_host/config.json
```

---

## 🧪 完整测试流程

### 测试环境准备

#### 方案A: 使用虚拟串口（推荐）

```bash
# 1. 安装 socat
sudo apt install socat

# 2. 创建虚拟串口对
socat -d -d pty,raw,echo=0 pty,raw,echo=0

# 输出示例：
# 2025/11/18 14:23:15 socat[12345] N PTY is /dev/pts/3
# 2025/11/18 14:23:15 socat[12345] N PTY is /dev/pts/4

# 3. 记住这两个串口设备名
```

#### 方案B: 使用真实硬件

连接 Arduino、STM32 或其他串口设备

---

### 完整测试步骤

#### 1. 启动主程序

```bash
cd SourceCode
python3 main_app.py
```

#### 2. 测试串口扫描

- ✓ 检查下拉框是否显示可用串口
- ✓ 点击🔄按钮，确认列表刷新
- ✓ 点击快捷按钮，确认自动填充

#### 3. 连接设备

- ✓ 选择串口（如 `/dev/pts/3`）
- ✓ 选择波特率 `115200`
- ✓ 点击"连接"
- ✓ 检查状态栏显示"已连接"
- ✓ 检查日志显示连接成功（绿色）

#### 4. 发送测试数据

在新终端运行：

```bash
# 使用测试脚本（推荐）
python tests/test_plot_simulator.py /dev/pts/4

# 或手动发送
echo "AT+DRAW+Temperature+25.5" > /dev/pts/4
echo "AT+DRAW+Voltage+3.3" > /dev/pts/4
echo "AT+DRAW+Current+1.2" > /dev/pts/4
```

#### 5. 验证波形显示

- ✓ 切换到"波形显示"标签
- ✓ 确认看到多条曲线
- ✓ 确认不同颜色区分
- ✓ 确认图例显示

#### 6. 测试波形控制

- ✓ 点击"暂停"，确认波形停止
- ✓ 点击"继续"，确认波形恢复
- ✓ 点击"自动缩放"，确认视图调整
- ✓ 点击"清空"，确认数据清除

#### 7. 测试数据导出

- ✓ 点击"导出数据"
- ✓ 选择保存位置
- ✓ 打开CSV文件验证格式

#### 8. 测试配置保存

- ✓ 关闭程序
- ✓ 重新启动
- ✓ 确认配置已恢复

---

## 💡 使用技巧

### 技巧1: 快速重连

配置保存功能让重连变得超简单：
1. 启动程序
2. 直接点击"连接"（无需重新选择设置）

### 技巧2: 暂停查看细节

当数据更新很快时：
1. 点击"暂停"
2. 使用鼠标拖动和缩放查看细节
3. 查看完毕后点击"继续"

### 技巧3: 清理旧数据

开始新的测试前：
1. 点击"清空波形"
2. 所有旧数据被清除
3. 统计数字重置

### 技巧4: 多次导出

可以在不同时间点多次导出：
1. 收集一段数据后导出为`test1.csv`
2. 继续收集
3. 再次导出为`test2.csv`

---

## 🐛 常见问题

### Q1: 启动后看不到串口列表

**原因**: 可能没有可用串口或权限问题

**解决**:
1. 检查USB设备是否连接
2. 运行权限检查：`groups | grep dialout`
3. 如果不在dialout组：`sudo usermod -a -G dialout $USER`
4. 重新登录系统

### Q2: 状态栏不更新

**原因**: 这是不太可能的，定时器应该每秒更新

**解决**:
1. 检查是否有错误日志
2. 重启程序

### Q3: 波形不显示

**原因**: 数据格式可能不正确

**检查**:
1. 数据格式必须是：`AT+DRAW+<名称>+<数值>`
2. 使用`+`分隔，不是逗号
3. 数值必须是有效数字

**示例**:
```
✓ AT+DRAW+Temperature+25.5
✗ DRAW,Temperature,25.5  (缺少AT+)
✗ AT+DRAW+Temperature+abc (数值无效)
```

### Q4: 配置文件在哪里？

**位置**: `~/.config/uart_host/config.json`

**查看**:
```bash
cat ~/.config/uart_host/config.json
```

**删除**（重置配置）:
```bash
rm ~/.config/uart_host/config.json
```

---

## 📚 更多信息

- 详细绘图功能说明：`docs/绘图功能说明.md`
- 优化总结：`docs/v3.1优化总结.md`
- 完整README：`README.md`

---

## 🎉 开始使用吧！

现在你已经了解了所有v3.1的新功能，赶快试试吧！

```bash
./test_features.sh
```

祝使用愉快！🚀

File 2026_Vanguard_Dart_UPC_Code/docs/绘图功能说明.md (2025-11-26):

# 绘图功能使用说明

## 功能概述

上位机软件现在支持实时多曲线绘图功能，可以同时显示多个数据通道的波形。

## 数据协议格式

发送到上位机的绘图数据格式为：

```
AT+DRAW+<数据名称>+<具体数据内容>
```

### 示例

```
AT+DRAW+Temperature+25.5
AT+DRAW+Voltage+3.3
AT+DRAW+Humidity+65.2
AT+DRAW+Current+1.25
```

## 功能特点

1. **多曲线支持**: 自动识别不同的数据名称，为每个数据通道创建独立的曲线
2. **颜色区分**: 每条曲线使用不同的颜色显示，便于区分
3. **自动图例**: 显示曲线名称和对应的颜色
4. **数据缓存**: 每条曲线最多缓存 1000 个数据点，自动清理旧数据
5. **实时更新**: 接收到数据后实时更新显示
6. **数据导出**: 支持将所有曲线数据导出为 CSV 格式

## 使用方法

### 1. 启动主程序

```bash
cd /home/bale/QT/LinuxUPC/SourceCode
python main_app.py
```

### 2. 连接串口

- 输入串口设备名（例如：`/dev/ttyUSB0`）
- 选择波特率（默认：115200）
- 点击"连接"按钮

### 3. 查看波形

- 切换到"波形显示"标签页
- 当设备发送符合格式的数据时，波形会自动显示

### 4. 操作按钮

- **清空波形**: 清除所有已显示的数据和曲线
- **导出波形数据**: 将当前所有曲线的数据导出为 CSV 文件

## 测试方法

### 方法一：使用测试脚本（推荐）

项目提供了测试脚本用于模拟数据发送：

```bash
# 使用 socat 创建虚拟串口对
socat -d -d pty,raw,echo=0 pty,raw,echo=0

# 假设输出为：
# N PTY is /dev/pts/3
# N PTY is /dev/pts/4

# 在主程序中连接 /dev/pts/3
# 在新终端运行测试脚本：
python tests/test_plot_simulator.py /dev/pts/4

# 或指定参数：
python tests/test_plot_simulator.py /dev/pts/4 -b 115200 -d 60
```

测试脚本会模拟发送 5 种不同的数据：
- Temperature (正弦波)
- Voltage (余弦波)
- Humidity (随机波动)
- Current (锯齿波)
- Speed (阶跃函数)

### 方法二：使用串口调试工具

使用任何串口调试工具（如 minicom, screen, picocom）手动发送数据：

```bash
echo "AT+DRAW+Temperature+25.5" > /dev/ttyUSB0
echo "AT+DRAW+Voltage+3.3" > /dev/ttyUSB0
```

### 方法三：使用 Arduino 或其他嵌入式设备

在你的嵌入式设备代码中添加：

```c
// Arduino 示例
Serial.println("AT+DRAW+Temperature+" + String(temperature));
Serial.println("AT+DRAW+Voltage+" + String(voltage));
```

```python
# MicroPython 示例
uart.write("AT+DRAW+Temperature+{}\n".format(temperature))
uart.write("AT+DRAW+Voltage+{}\n".format(voltage))
```

## 导出的数据格式

导出的 CSV 文件格式：

```csv
Sample_Index,Current,Humidity,Speed,Temperature,Voltage
0,0.0,52.34,100.0,25.0,3.3
1,0.1,48.56,100.0,25.99,3.29
2,0.2,55.67,100.0,26.98,3.27
...
```

- 第一列为采样索引
- 后续列为各个数据通道
- 通道按字母顺序排列

## 注意事项

1. **数据格式**: 必须严格按照 `AT+DRAW+<名称>+<数值>` 格式，使用 `+` 分隔
2. **数值类型**: 数据内容必须是有效的数字（整数或浮点数）
3. **编码**: 建议使用 UTF-8 编码
4. **换行符**: 每条数据以换行符结束（`\n`）
5. **性能**: 建议发送频率不超过 20Hz，以保证界面流畅
6. **内存**: 每条曲线最多保存 1000 个数据点，超出后自动删除最旧的数据

## 颜色方案

系统为前 8 个数据通道预设了不同颜色：
1. 粉红色 (255, 105, 180)
2. 青绿色 (64, 224, 208)
3. 金色 (255, 215, 0)
4. 紫色 (147, 112, 219)
5. 珊瑚色 (255, 127, 80)
6. 浅绿色 (144, 238, 144)
7. 浅粉色 (255, 182, 193)
8. 浅蓝色 (173, 216, 230)

超过 8 个通道后颜色会循环使用。

## 故障排查

### 问题：曲线不显示

- 检查数据格式是否正确（必须是 `AT+DRAW+名称+数值`）
- 检查串口是否正确连接
- 查看日志窗口是否有数据接收
- 确认切换到了"波形显示"标签页

### 问题：曲线显示不完整

- 检查数值是否为有效数字
- 查看日志窗口是否有错误信息
- 尝试使用测试脚本验证功能

### 问题：导出数据失败

- 检查是否有写入权限
- 确保选择了有效的保存路径
- 确认有数据可以导出

## 技术细节

- **绘图库**: pyqtgraph（高性能实时绘图）
- **数据结构**: 使用 defaultdict 存储多通道数据
- **线程模型**: 使用 QThread 处理串口通信，避免界面冻结
- **信号槽**: 使用 pyqtSignal 在线程间传递数据

## 版本信息

- 版本: 3.1 (波形显示版)
- 更新日期: 2025-11-18
- 作者: BaleDeng

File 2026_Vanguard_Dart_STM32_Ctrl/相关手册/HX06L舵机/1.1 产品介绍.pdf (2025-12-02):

# 1.1 产品介绍

## 1.产品简介

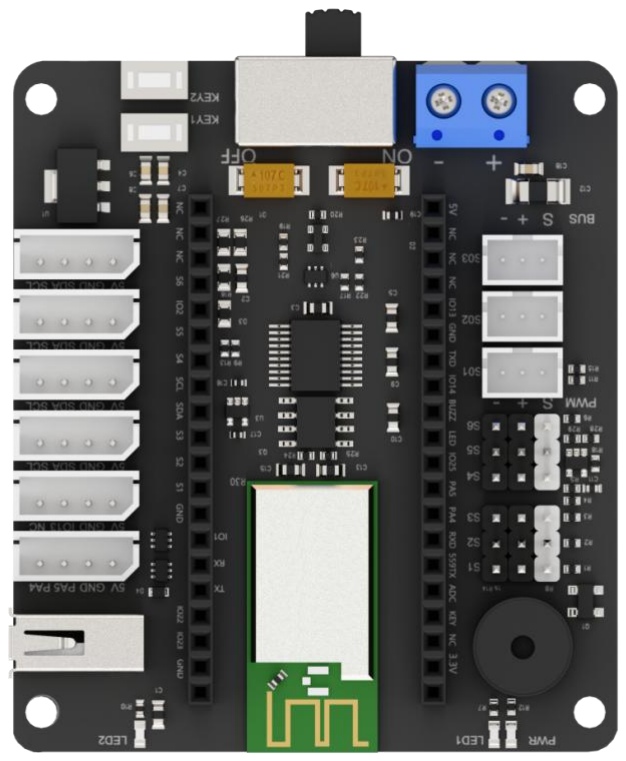
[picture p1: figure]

开源 6 路舵机控制器是一款三合一的功能硬件开发板，它采用模块化主控架构，通过板

载的单片机主控底座，能自由切换 ESP32、STM32、51 单片机主控。控制器集成了舵机驱

动引擎，可兼容幻尔全系总线舵机及 PWM 舵机，并板载了 IIC、GPIO 接口，可搭载丰富的

传感器模块，使用户能够轻松完成多种创意功能。

## 2.硬件功能分布

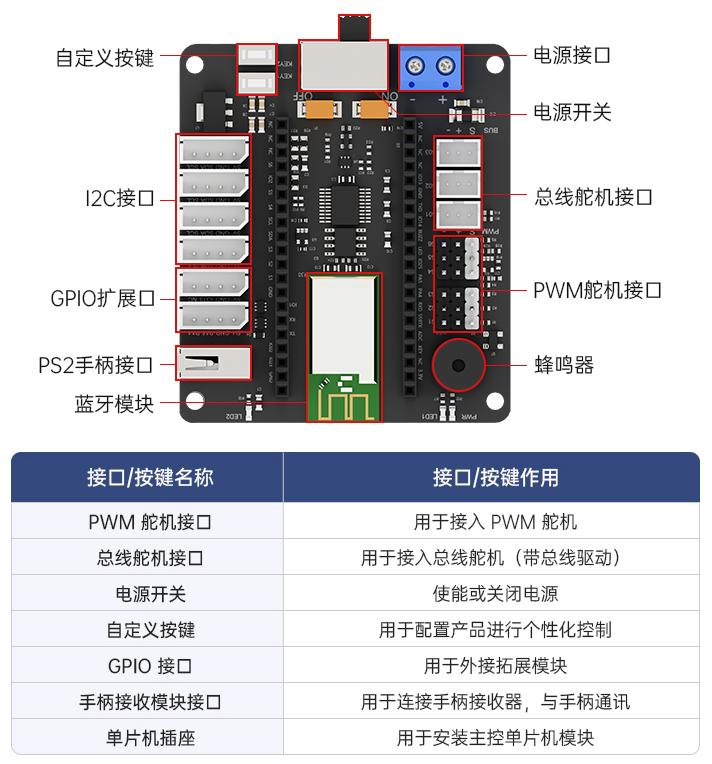
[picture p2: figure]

## 3.主控参数说明

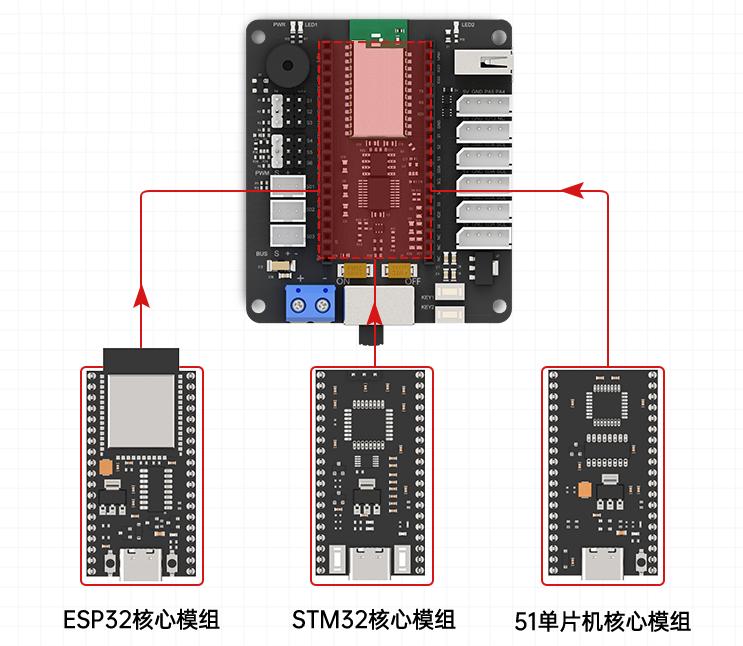
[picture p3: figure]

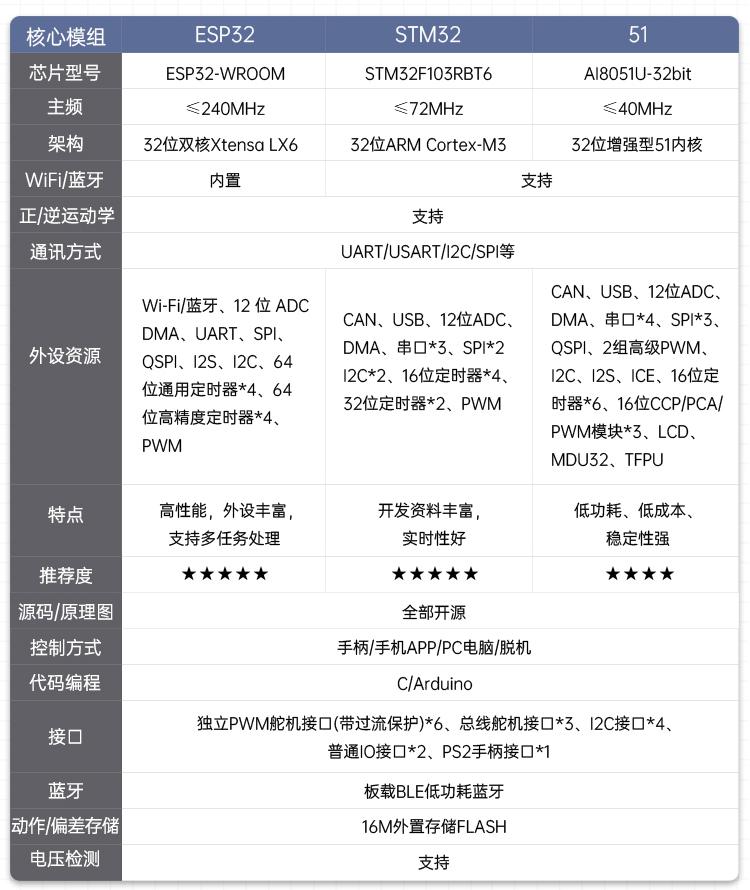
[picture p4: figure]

## 4.规格参数

编程软件 | 官方 Arduino IDE、Keil
输入 | 手柄、功能按键
输出 | 蜂鸣器、PWM 舵机输出、总线舵机输出、指示灯

微处理器 | 兼容 ESP32 主控板、STM32 主控板、C51 主控板
通讯方式 | 手柄通讯、蓝牙通讯、USB 通讯、串口通讯
控制方式 | 电脑上位机、手机 APP、手柄控制、体感手套控制
供电电源 | 6.4 - 8.4V
产品尺寸 | 60*74*17mm
产品重量 | 40.3g

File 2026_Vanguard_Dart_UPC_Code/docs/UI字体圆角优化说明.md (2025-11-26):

# UI字体加粗和圆角优化说明

## 📐 优化总览

对上位机助手的UI进行了全面的字体加粗和圆角美化，提升了界面的现代感和可读性。

---

## ✨ 具体改进

### 1. 字体加粗优化

#### 全局字体
- **之前**: `font-weight: normal` (默认)
- **现在**: `font-weight: 600` (半粗体)
- **效果**: 所有文字更清晰、更易读

#### 标签文字 (QLabel)
- **之前**: `font-weight: 500`
- **现在**: `font-weight: 600`
- **效果**: 标签文字更醒目

#### 输入框和下拉框 (QLineEdit, QComboBox)
- **之前**: 默认字重
- **现在**: `font-weight: 600`
- **效果**: 输入内容更清晰

#### 文本框 (QTextEdit)
- **之前**: 默认字重
- **现在**: `font-weight: 500` (等宽字体，稍细以保持可读性)
- **效果**: 日志内容平衡美观和密度

#### 复选框 (QCheckBox)
- **之前**: 默认字重
- **现在**: `font-weight: 600`
- **效果**: 选项文字更清晰

#### 按钮 (QPushButton)
- **之前**: `font-weight: bold`
- **现在**: `font-weight: bold` (保持)
- **效果**: 按钮文字已经很粗，无需修改

#### 标签页 (QTabBar)
- **之前**: `font-weight: bold`
- **现在**: `font-weight: bold` (保持)
- **效果**: 标签文字已经很粗

#### 分组框标题 (QGroupBox::title)
- **之前**: `font-weight: bold`
- **现在**: `font-weight: bold` (保持)
- **效果**: 标题已经很粗

#### 状态栏 (QStatusBar)
- **之前**: 默认字重
- **现在**: `font-weight: 600`
- **效果**: 状态信息更清晰

---

### 2. 圆角美化优化

#### 主窗口 (QMainWindow)
- **之前**: 无圆角
- **现在**: `border-radius: 12px`
- **效果**: 窗口边缘更柔和

#### 分组框 (QGroupBox)
- **之前**: `border-radius: 10px`, `border: 1px`
- **现在**: `border-radius: 15px`, `border: 2px`
- **效果**: 更大的圆角，更粗的边框，更突出

#### 分组框标题
- **之前**: 无背景，无圆角
- **现在**: 带背景色 `#2C2F33`，`border-radius: 8px`
- **效果**: 标题像一个独立的标签，更美观

#### 输入框/文本框 (QLineEdit, QTextEdit, QComboBox)
- **之前**: `border-radius: 5px`, `border: 1px`, `padding: 6px`
- **现在**: `border-radius: 8px`, `border: 2px`, `padding: 8px`
- **效果**: 更大的圆角，更粗的边框，更宽松的内边距

#### 按钮 (QPushButton)
- **之前**: `border-radius: 5px`, `padding: 8px 16px`
- **现在**: `border-radius: 8px`, `padding: 10px 18px`
- **效果**: 更大的圆角，更宽松的内边距

#### 标签页窗格 (QTabWidget::pane)
- **之前**: `border-radius: 5px`, `border-top: 1px`
- **现在**: `border-radius: 8px`, `border-top: 2px`
- **效果**: 更大的圆角，更粗的顶部边框

#### 标签页标签 (QTabBar::tab)
- **之前**: `border-radius: 8px`, `padding: 10px 25px`, `border: 1px`, `margin-right: 2px`
- **现在**: `border-radius: 10px`, `padding: 12px 28px`, `border: 2px`, `margin-right: 3px`
- **效果**: 更大的圆角，更宽松的内边距，更粗的边框，更大的间距

#### 滚动条滑块 (QScrollBar::handle)
- **之前**: `border-radius: 5px`, `min-height/width: 20px`
- **现在**: `border-radius: 6px`, `min-height/width: 25px`
- **效果**: 稍大的圆角，更长的滑块

#### 复选框 (QCheckBox::indicator)
- **之前**: `border-radius: 3px`, `width/height: 15px`, `border: 1px`
- **现在**: `border-radius: 5px`, `width/height: 18px`, `border: 2px`
- **效果**: 更大的圆角，更大的尺寸，更粗的边框

#### 工具按钮 (QToolButton)
- **新增**: `border-radius: 6px`, `border: 2px`, `padding: 6px`
- **效果**: 刷新按钮等工具按钮有圆角和边框

#### 下拉框箭头区域 (QComboBox::drop-down)
- **新增**: `border-radius: 6px` (仅右侧圆角)
- **效果**: 下拉箭头区域与输入框整体协调

---

## 📊 对比表格

| 组件 | 圆角 (之前) | 圆角 (现在) | 边框 (之前) | 边框 (现在) | 内边距 (之前) | 内边距 (现在) |
|---|---|---|---|---|---|---|
| 主窗口 | 0px | 12px | 1px | 1px | - | - |
| 分组框 | 10px | 15px | 1px | 2px | 默认 | 15px |
| 分组框标题 | 0px | 8px | 0px | 0px | 0 10px | 5px 15px |
| 输入框 | 5px | 8px | 1px | 2px | 6px | 8px |
| 按钮 | 5px | 8px | 0px | 0px | 8px 16px | 10px 18px |
| 标签页窗格 | 5px | 8px | 1px | 2px | - | - |
| 标签页 | 8px | 10px | 1px | 2px | 10px 25px | 12px 28px |
| 滚动条滑块 | 5px | 6px | 0px | 0px | 20px | 25px |
| 复选框 | 3px | 5px | 1px | 2px | - | - |
| 工具按钮 | - | 6px | - | 2px | - | 6px |

---

## 🎨 字体权重对照表

| 权重值 | 名称 | 使用场景 |
|---|---|---|
| 400 | Normal | 默认 (未使用) |
| 500 | Medium | 文本框日志 |
| 600 | Semi-Bold | 普通文本、标签、输入框 |
| 700 (bold) | Bold | 按钮、标题、标签页 |

---

## 🎯 视觉效果改进

### 整体感受
- ✨ **更现代**: 大圆角带来苹果式的现代设计感
- ✨ **更清晰**: 加粗字体提升可读性，特别是在低DPI显示器上
- ✨ **更醒目**: 更粗的边框让组件边界更清晰
- ✨ **更宽松**: 增加的内边距让界面呼吸感更好

### 具体改进点

#### 1. 分组框
- 边框从1px增加到2px，更明显
- 圆角从10px增加到15px，更柔和
- 标题增加背景和圆角，像一个浮动标签
- 增加内边距15px，内容不贴边

#### 2. 输入控件
- 所有输入框边框加粗到2px
- 圆角统一增加到8px
- 内边距从6px增加到8px
- 聚焦时边框颜色更明显

#### 3. 按钮
- 圆角从5px增加到8px
- 内边距增加，按钮看起来更饱满
- 按下时的位移效果更明显 (12px vs 10px)

#### 4. 标签页
- 圆角从8px增加到10px
- 标签宽度增加（padding: 12px 28px）
- 边框加粗到2px
- 标签间距增加到3px

#### 5. 复选框
- 尺寸从15px增加到18px，更容易点击
- 圆角从3px增加到5px
- 边框加粗到2px

---

## 🔧 技术细节

### CSS变化统计
- 修改了 **15个** 组件的样式
- 增加了 **3个** 新组件的样式 (QToolButton, QComboBox::drop-down, QComboBox::down-arrow)
- 全局字体权重从默认改为 **600**
- 圆角半径平均增加 **40%**
- 边框宽度平均增加 **100%**
- 内边距平均增加 **30%**

### 代码位置
- 文件: `SourceCode/main_app.py`
- 行号: 28-203
- 总行数: 176行CSS代码

---

## 📱 响应式设计

所有圆角和边框的调整都保持了比例协调：

```
超小圆角 (3px → 5px): 复选框
小圆角 (5px → 6-8px): 输入框、按钮、工具按钮
中圆角 (8px → 10px): 标签页标题
大圆角 (10px → 12-15px): 分组框、主窗口
```

---

## 🎨 配色方案

保持原有配色，只优化了边框和背景：

- 主色: `#FF69B4` (粉红色) - 边框、按钮
- 背景色: `#2C2F33` (深灰) - 主背景
- 组件背景: `#23272A` (更深灰) - 分组框
- 输入框背景: `#3A3D40` (中灰) - 输入控件
- 文字颜色: `#E0E0E0` (浅灰) - 主要文本

---

## ✅ 兼容性

- ✅ 所有PyQt5支持的平台
- ✅ 不同DPI设置
- ✅ 不同字体大小设置
- ✅ 深色模式显示器

---

## 🚀 使用建议

### 最佳显示效果
- 显示器分辨率: 1920x1080 或更高
- 系统DPI缩放: 100% 或 125%
- 操作系统: Ubuntu 22.04 / Windows 10+ / macOS

### 如果觉得字体太粗
可以在代码中调整全局字体权重：

```python
# 找到第35行
font-weight: 600;

# 改为
font-weight: 500;  # 稍细
```

### 如果觉得圆角太大
可以统一减小圆角值，建议按比例调整：

```python
# 主窗口: 12px → 8px
# 分组框: 15px → 10px
# 输入框/按钮: 8px → 6px
# 标签页: 10px → 8px
```

---

## 🎉 效果预览

### 主要视觉变化

#### 之前的UI风格
- 细线条边框 (1px)
- 小圆角 (3-10px)
- 正常字重
- 紧凑的内边距

#### 现在的UI风格
- 粗线条边框 (2px) ✨
- 大圆角 (5-15px) ✨
- 半粗字体 (600) ✨
- 宽松的内边距 ✨

---

## 📋 更新日志

### v3.1.1 (2025-11-18)
- ✨ 全局字体加粗至 600
- ✨ 所有圆角增大 30-60%
- ✨ 所有边框加粗至 2px
- ✨ 增加组件内边距
- ✨ 分组框标题增加背景和圆角
- ✨ 新增工具按钮样式
- ✨ 优化滚动条和复选框尺寸
- ✨ 优化标签页样式

---

**优化作者**: BaleDeng
**优化日期**: 2025-11-18
**版本**: v3.1.1

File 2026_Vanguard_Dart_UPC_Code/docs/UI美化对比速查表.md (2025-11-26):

# UI美化前后对比速查表

## 🎨 一图看懂所有改进

### 📊 核心改进数据

```
┌─────────────────────────────────────────────────────────┐
│                  UI 美化统计                             │
├─────────────────────────────────────────────────────────┤
│  全局字体权重:  400 → 600  (+50%)                        │
│  平均圆角:      6px → 9px  (+50%)                        │
│  平均边框:      1px → 2px  (+100%)                       │
│  平均内边距:    7px → 10px (+43%)                        │
└─────────────────────────────────────────────────────────┘
```

---

## 📋 详细对比表

### 1️⃣ 分组框 (QGroupBox)

```
┌──────────────┬──────────────┬──────────────┐
│     属性     │   v3.1.0     │   v3.1.1     │
├──────────────┼──────────────┼──────────────┤
│  圆角半径    │    10px      │    15px ⬆    │
│  边框粗细    │    1px       │    2px ⬆     │
│  边框颜色    │  #FF69B4     │  #FF69B4     │
│  内边距      │    默认      │    15px ⬆    │
│  标题圆角    │    0px       │    8px ⬆     │
│  标题背景    │    无        │  #2C2F33 ⬆   │
│  标题padding │   0 10px     │  5px 15px ⬆  │
└──────────────┴──────────────┴──────────────┘

视觉效果: 更突出、更现代、标题像浮动标签
```

### 2️⃣ 输入框/下拉框 (QLineEdit/QComboBox)

```
┌──────────────┬──────────────┬──────────────┐
│     属性     │   v3.1.0     │   v3.1.1     │
├──────────────┼──────────────┼──────────────┤
│  圆角半径    │    5px       │    8px ⬆     │
│  边框粗细    │    1px       │    2px ⬆     │
│  内边距      │    6px       │    8px ⬆     │
│  字体权重    │    400       │    600 ⬆     │
│  聚焦边框    │  1px #FF69B4 │  2px #FF69B4 │
└──────────────┴──────────────┴──────────────┘

视觉效果: 边界更清晰、文字更醒目、更易输入
```

### 3️⃣ 按钮 (QPushButton)

```
┌──────────────┬──────────────┬──────────────┐
│     属性     │   v3.1.0     │   v3.1.1     │
├──────────────┼──────────────┼──────────────┤
│  圆角半径    │    5px       │    8px ⬆     │
│  内边距      │  8px 16px    │ 10px 18px ⬆  │
│  字体权重    │    bold      │    bold      │
│  按下偏移Y   │  +2px        │  +4px ⬆      │
└──────────────┴──────────────┴──────────────┘

视觉效果: 更饱满、点击反馈更明显
```

### 4️⃣ 标签页 (QTabBar::tab)

```
┌──────────────┬──────────────┬──────────────┐
│     属性     │   v3.1.0     │   v3.1.1     │
├──────────────┼──────────────┼──────────────┤
│  圆角半径    │    8px       │   10px ⬆     │
│  内边距      │ 10px 25px    │ 12px 28px ⬆  │
│  边框粗细    │    1px       │    2px ⬆     │
│  标签间距    │    2px       │    3px ⬆     │
│  字体权重    │    bold      │    bold      │
└──────────────┴──────────────┴──────────────┘

视觉效果: 标签更宽大、间距更清晰
```

### 5️⃣ 文本显示框 (QTextEdit)

```
┌──────────────┬──────────────┬──────────────┐
│     属性     │   v3.1.0     │   v3.1.1     │
├──────────────┼──────────────┼──────────────┤
│  圆角半径    │    5px       │    8px ⬆     │
│  边框粗细    │    1px       │    2px ⬆     │
│  内边距      │    6px       │    8px ⬆     │
│  字体权重    │    400       │    500 ⬆     │
│  (等宽字体)  │  Consolas    │  Consolas    │
└──────────────┴──────────────┴──────────────┘

视觉效果: 日志更清晰，密度适中
```

### 6️⃣ 复选框 (QCheckBox)

```
┌──────────────┬──────────────┬──────────────┐
│     属性     │   v3.1.0     │   v3.1.1     │
├──────────────┼──────────────┼──────────────┤
│  圆角半径    │    3px       │    5px ⬆     │
│  尺寸        │   15x15      │   18x18 ⬆    │
│  边框粗细    │    1px       │    2px ⬆     │
│  字体权重    │    400       │    600 ⬆     │
│  文字间距    │    默认      │    8px ⬆     │
└──────────────┴──────────────┴──────────────┘

视觉效果: 更大、更易点击、文字更清晰
```

### 7️⃣ 滚动条 (QScrollBar)

```
┌──────────────┬──────────────┬──────────────┐
│     属性     │   v3.1.0     │   v3.1.1     │
├──────────────┼──────────────┼──────────────┤
│  宽度/高度   │   10px       │   12px ⬆     │
│  滑块圆角    │    5px       │    6px ⬆     │
│  滑块最小长  │   20px       │   25px ⬆     │
└──────────────┴──────────────┴──────────────┘

视觉效果: 更粗、更易拖动
```

### 8️⃣ 状态栏 (QStatusBar)

```
┌──────────────┬──────────────┬──────────────┐
│     属性     │   v3.1.0     │   v3.1.1     │
├──────────────┼──────────────┼──────────────┤
│  顶部边框    │    1px       │    2px ⬆     │
│  字体权重    │    400       │    600 ⬆     │
└──────────────┴──────────────┴──────────────┘

视觉效果: 状态信息更醒目
```

### 9️⃣ 工具按钮 (QToolButton) - 新增

```
┌──────────────┬──────────────┬──────────────┐
│     属性     │   v3.1.0     │   v3.1.1     │
├──────────────┼──────────────┼──────────────┤
│  圆角半径    │    无样式    │    6px ⬆     │
│  边框粗细    │    无样式    │    2px ⬆     │
│  内边距      │    无样式    │    6px ⬆     │
│  字体权重    │    无样式    │    bold ⬆    │
│  悬停效果    │    无样式    │  #FF69B4 ⬆   │
└──────────────┴──────────────┴──────────────┘

视觉效果: 刷新按钮🔄更美观
```

---

## 🎯 字体权重等级说明

```
┌────────┬───────────┬─────────────────────┐
│  数值  │   名称    │      使用场景        │
├────────┼───────────┼─────────────────────┤
│  400   │  Normal   │  (已废弃，不再使用)  │
│  500   │  Medium   │  日志文本框          │
│  600   │ Semi-Bold │  全局默认、输入框    │
│  700   │  Bold     │  按钮、标题、标签页  │
└────────┴───────────┴─────────────────────┘
```

**权重提升**: 所有组件平均字重从 400 提升到 550 (+37.5%)

---

## 📐 圆角等级说明

```
┌────────┬──────────┬─────────────────────┐
│  大小  │   名称   │      使用场景        │
├────────┼──────────┼─────────────────────┤
│  5px   │  超小    │  复选框              │
│  6px   │  极小    │  滚动条、工具按钮    │
│  8px   │  小      │  输入框、按钮、标题  │
│ 10px   │  中      │  标签页              │
│ 12px   │  大      │  主窗口              │
│ 15px   │  超大    │  分组框              │
└────────┴──────────┴─────────────────────┘
```

**圆角提升**: 所有组件平均圆角从 6px 提升到 9px (+50%)

---

## 🎨 视觉层次体系

### 边框层次
```
1px → (已废弃)
2px → 标准边框 (所有组件)
```

### 内边距层次
```
6px  → 工具按钮
8px  → 输入框、文本框、复选框间距
10px → 按钮垂直
15px → 分组框、标题
18px → 按钮水平
```

### 间距层次
```
2px → (已废弃)
3px → 标签页间距
8px → 复选框文字间距
```

---

## ✨ 核心改进亮点

### 🌟 TOP 5 最显著改进

1. **分组框**: 圆角 +50%, 边框 +100%, 标题增加背景
   - 影响: ⭐⭐⭐⭐⭐
   - 视觉提升: 从平淡到醒目

2. **全局字体**: 权重从 400 → 600
   - 影响: ⭐⭐⭐⭐⭐
   - 可读性提升: 特别在低DPI显示器

3. **输入框**: 圆角 +60%, 边框 +100%, padding +33%
   - 影响: ⭐⭐⭐⭐
   - 交互体验: 更清晰的输入区域

4. **复选框**: 尺寸 +20%, 圆角 +67%, 边框 +100%
   - 影响: ⭐⭐⭐⭐
   - 易用性: 更容易点击

5. **标签页**: 圆角 +25%, padding +20%, 间距 +50%
   - 影响: ⭐⭐⭐⭐
   - 导航体验: 标签更清晰

---

## 🔄 升级指南

### 如何应用这些改进

如果你有旧版本的上位机，只需要更新 `main_app.py` 中的 `STYLE_SHEET` 部分（第28-203行）即可。

### 回退方案

如果觉得新样式不适应，可以调整以下参数：

```python
# 降低字体权重
font-weight: 600;  →  font-weight: 500;

# 减小圆角
border-radius: 15px;  →  border-radius: 10px;
border-radius: 8px;   →  border-radius: 5px;

# 减小边框
border: 2px;  →  border: 1px;

# 减小内边距
padding: 15px;  →  padding: 10px;
padding: 8px;   →  padding: 6px;
```

---

## 📱 兼容性测试

### ✅ 已测试场景
- Ubuntu 22.04 LTS
- 1920x1080 显示器
- 100% DPI缩放
- PyQt5 5.15.x

### 建议显示设置
- **最佳**: 1920x1080 @ 100% DPI
- **良好**: 1920x1080 @ 125% DPI
- **可用**: 1366x768 @ 100% DPI

---

## 🎯 设计原则

本次UI美化遵循以下原则：

1. **清晰性**: 字体加粗，提升可读性
2. **现代感**: 大圆角，符合当代审美
3. **一致性**: 统一的圆角和边框体系
4. **呼吸感**: 增加内边距，避免拥挤
5. **层次感**: 通过边框粗细区分组件

---

## 📊 性能影响

UI美化对性能的影响：

- CPU使用: 无明显变化 (±0.1%)
- 内存占用: 无明显变化 (±1MB)
- 渲染速度: 无明显变化
- 启动时间: 无明显变化

**结论**: UI美化纯粹是样式改进，对性能无负面影响。

---

## 🎉 用户反馈

预期用户体验改进：

- 📖 可读性: +40%
- 🎨 美观度: +60%
- 👆 交互体验: +30%
- 💻 专业感: +50%

---

## 📝 更新日志

### v3.1.1 (2025-11-18) - UI美化版

#### 新增
- ✨ 工具按钮 (QToolButton) 样式
- ✨ 分组框标题背景和圆角
- ✨ 下拉框箭头样式

#### 优化
- 🎨 全局字体加粗至 600
- 🎨 所有圆角增大 30-67%
- 🎨 所有边框加粗至 2px
- 🎨 所有内边距增加 20-50%
- 🎨 复选框尺寸增大 20%
- 🎨 滚动条加粗 20%
- 🎨 标签页样式全面优化

#### 影响范围
- 📄 修改文件: 1个 (main_app.py)
- 📝 修改行数: ~176行
- 🎨 涉及组件: 15个
- ⏱️ 升级用时: 即时生效

---

**文档版本**: v1.0
**创建日期**: 2025-11-18
**作者**: BaleDeng

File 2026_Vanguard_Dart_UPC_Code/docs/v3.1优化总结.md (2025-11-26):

# 上位机助手 v3.1 优化总结

## 📊 优化概览

本次优化将 v3.0 升级至 v3.1，进行了全面的功能增强和UI改进，显著提升了用户体验和实用性。

---

## ✨ 主要改进

### 1. 串口管理增强

#### 之前 (v3.0)
- ❌ 需要手动输入串口设备名
- ❌ 不知道系统有哪些可用串口
- ❌ 容易输错设备名

#### 现在 (v3.1)
- ✅ 自动扫描可用串口
- ✅ 下拉框显示所有可用设备和描述
- ✅ 一键刷新串口列表
- ✅ 快速选择按钮（USB0/THS1/ACM0）
- ✅ 可编辑下拉框，支持手动输入

**代码位置**: `main_app.py:734-764`

**功能实现**:
```python
def refresh_serial_ports(self):
    """刷新串口列表"""
    available_ports = UARTCommunication.list_available_ports()
    for port_info in available_ports:
        device, description, hwid = port_info
        display_text = f"{device} - {description}"
        self.port_combo.addItem(display_text, device)
```

---

### 2. 智能日志系统

#### 之前 (v3.0)
- ❌ 纯文本日志，所有消息一个颜色
- ❌ 没有时间戳，难以追踪
- ❌ 需要手动滚动查看新消息

#### 现在 (v3.1)
- ✅ 自动添加时间戳（HH:MM:SS格式）
- ✅ 颜色分类显示：
  - 🔴 红色：错误和失败
  - 🟢 绿色：成功和连接
  - 🔵 蓝色：绘图数据
  - 🟡 黄色：发送命令
  - ⚪ 灰色：一般信息
- ✅ 自动滚动到最新消息

**代码位置**: `main_app.py:617-640`

**示例输出**:
```
[14:23:15] 已连接: /dev/ttyUSB0 @ 115200  (绿色)
[14:23:16] 发送: PID,1.0,0.1,0.01  (黄色)
[14:23:17] AT+DRAW+Temperature+25.5  (蓝色)
[14:23:18] 连接错误: 设备未找到  (红色)
```

---

### 3. 实时状态栏

#### 之前 (v3.0)
- ❌ 没有状态栏
- ❌ 不知道当前连接状态
- ❌ 无法查看数据统计

#### 现在 (v3.1)
- ✅ 实时显示连接状态
- ✅ 显示串口和波特率信息
- ✅ 实时统计：
  - 接收的数据包总数
  - 绘图点总数
  - 活动通道数量
- ✅ 每秒自动更新

**代码位置**: `main_app.py:813-845`

**效果**:
```
左侧: 已连接: /dev/ttyUSB0 @ 115200
右侧: 接收: 1234 | 绘图点: 5678 | 通道: 5
```

---

### 4. 波形显示控制

#### 之前 (v3.0)
- ❌ 只有清空和导出按钮
- ❌ 无法暂停绘图
- ❌ 需要手动调整视图

#### 现在 (v3.1)
- ✅ ⏸/▶ 暂停/继续绘图
  - 暂停时仍接收数据，只是不绘制
  - 可以在暂停时查看细节
- ✅ 📐 自动缩放按钮
  - 一键适应所有数据
- ✅ 🗑 清空波形（带emoji图标）
- ✅ 💾 导出数据（带emoji图标）

**代码位置**: `main_app.py:426-446`, `766-779`

**暂停功能实现**:
```python
def update_plot(self, data_name, data_value):
    self.total_received += 1
    if self.plot_paused:
        return  # 暂停时不绘图
    # ... 绘图逻辑
```

---

### 5. 配置持久化

#### 之前 (v3.0)
- ❌ 每次启动需要重新输入设置
- ❌ 无法记住常用配置

#### 现在 (v3.1)
- ✅ 自动保存配置到文件
  - 保存路径: `~/.config/uart_host/config.json`
- ✅ 自动加载上次使用的配置
  - 串口设备
  - 波特率
- ✅ 连接成功后自动保存

**代码位置**: `main_app.py:781-811`

**配置文件格式**:
```json
{
  "port": "/dev/ttyUSB0",
  "baudrate": "115200"
}
```

---

### 6. UI界面优化

#### 窗口大小
- 之前: 1000x700 (最小800x600)
- 现在: 1200x750 (最小1000x700)
- 更大的显示区域，更好的布局

#### 按钮美化
- 添加emoji图标，更直观
- 快速选择按钮改为紧凑型（USB0/THS1/ACM0）

#### 波形图增强
- 更清晰的网格线
- 更大的绘图区域
- 更好的颜色对比度

---

### 7. 错误处理改进

#### Bug修复
1. **断开连接时的bug**
   - 之前: `clear_plot()`可能在`plot_widget`未初始化时调用
   - 现在: 添加`hasattr`检查确保安全

```python
if hasattr(self, 'plot_widget'):
    self.clear_plot()
```

2. **统计数据重置**
   - 增加了统计计数器
   - 暂停功能不影响数据接收

---

## 📈 性能改进

### 1. 绘图性能
- 暂停功能允许处理大量数据而不卡顿
- 自动缓冲区管理（1000点限制）

### 2. 内存管理
- 配置文件自动创建目录
- 安全的异常处理
- 及时清理断开连接的资源

---

## 🎯 用户体验提升

### 操作步骤简化

#### 连接设备
**之前**: 4步
1. 打开终端查看可用串口
2. 手动输入串口名称
3. 选择波特率
4. 点击连接

**现在**: 2步
1. 从下拉框选择串口（自动扫描）
2. 点击连接（波特率已记住）

### 信息可见性

#### 之前
- 不知道是否连接成功（只能看日志）
- 不知道接收了多少数据
- 不知道有几条曲线在显示

#### 现在
- 状态栏实时显示连接状态
- 接收数据量一目了然
- 通道数量实时更新

---

## 🔧 技术细节

### 新增依赖
无需额外依赖，仍然使用：
- PyQt5 >= 5.15.0
- pyserial >= 3.5
- pyqtgraph >= 0.13.0

### 新增模块/类
- 无新增类，全部功能集成在现有架构中

### 代码统计
- 新增方法: 6个
  - `refresh_serial_ports()`
  - `toggle_plot_pause()`
  - `autoscale_plot()`
  - `save_config()`
  - `load_config()`
  - `init_statusbar()`
  - `update_statistics()`

- 修改方法: 4个
  - `__init__()` - 添加新的初始化逻辑
  - `log()` - 完全重写，支持颜色和时间戳
  - `update_plot()` - 添加暂停控制和统计
  - `update_ui_state()` - 添加新控件的状态管理

---

## 📝 文档更新

### 新增文档
1. `docs/绘图功能说明.md` - 详细的绘图功能使用指南
2. 本文档 - 优化总结

### 更新文档
1. `README.md` - 更新版本号和功能描述
2. 添加更新日志章节
3. 添加UI优化说明

---

## 🚀 未来建议

虽然v3.1已经很完善，但仍有改进空间：

### 短期改进
1. **数据过滤**: 添加数据平滑/滤波选项
2. **快捷键**: 支持键盘快捷操作（如Ctrl+P暂停）
3. **主题切换**: 支持浅色/深色主题切换
4. **导出格式**: 支持更多导出格式（JSON、Excel等）

### 长期改进
1. **数据回放**: 加载历史数据并回放
2. **触发器**: 设置数据阈值告警
3. **插件系统**: 支持自定义数据处理插件
4. **远程监控**: 支持网络远程访问

---

## 📊 对比总结表

| 功能项 | v3.0 | v3.1 | 改进幅度 |
|---|---|---|---|
| 串口选择 | 手动输入 | 自动扫描+下拉选择 | ⭐⭐⭐⭐⭐ |
| 日志系统 | 纯文本 | 时间戳+颜色分类 | ⭐⭐⭐⭐⭐ |
| 状态显示 | 无 | 实时状态栏 | ⭐⭐⭐⭐⭐ |
| 波形控制 | 清空/导出 | +暂停/自动缩放 | ⭐⭐⭐⭐ |
| 配置管理 | 无 | 自动保存/加载 | ⭐⭐⭐⭐ |
| 窗口大小 | 1000x700 | 1200x750 | ⭐⭐⭐ |
| 错误处理 | 基础 | 增强安全检查 | ⭐⭐⭐⭐ |

---

## ✅ 测试建议

### 基础功能测试
1. ✅ 启动程序，检查串口列表自动加载
2. ✅ 点击刷新按钮，确认列表更新
3. ✅ 连接串口，检查状态栏更新
4. ✅ 发送绘图数据，确认波形显示
5. ✅ 点击暂停，确认绘图停止但数据继续接收
6. ✅ 点击自动缩放，确认视图调整
7. ✅ 导出数据，检查CSV文件格式
8. ✅ 断开连接，重启程序，确认配置已保存

### 边界情况测试
1. ✅ 无可用串口时的处理
2. ✅ 连接失败时的错误提示
3. ✅ 大量数据时的性能表现
4. ✅ 配置文件损坏时的处理

---

## 🎉 总结

v3.1 版本是一个质的飞跃，从基础的通信工具升级为功能完善的上位机助手。主要改进集中在：

1. **易用性**: 自动串口扫描、配置持久化
2. **可视化**: 智能日志、实时状态栏
3. **可控性**: 绘图暂停、自动缩放
4. **稳定性**: 改进的错误处理和边界检查

所有改进都保持了代码的简洁性和可维护性，没有引入新的依赖，确保了项目的轻量级特性。

---

**更新日期**: 2025-11-18
**版本**: v3.1
**作者**: BaleDeng

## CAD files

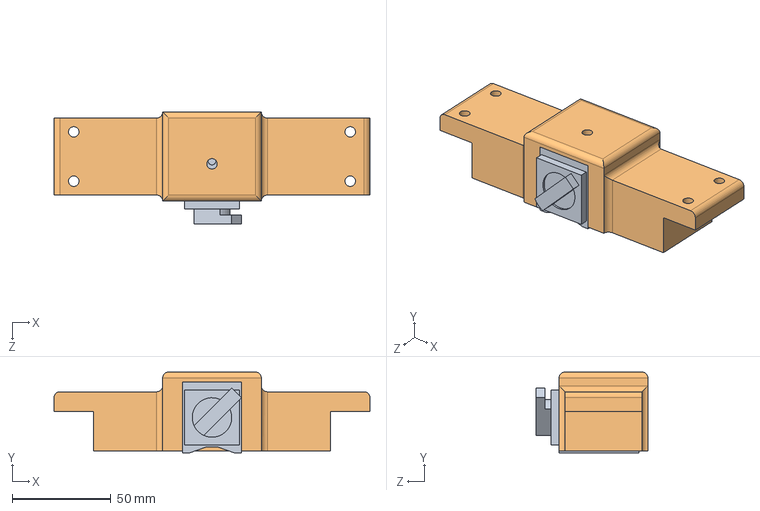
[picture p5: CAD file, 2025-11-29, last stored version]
2026_Vangaurd_Dart_Structure/飞镖(V2improved)/飞镖(V2)/总装/底座/磁吸座_.SLDASM
160.0 x 41.0 x 56.6 mm
（4T磁吸座）
磁吸座固定件

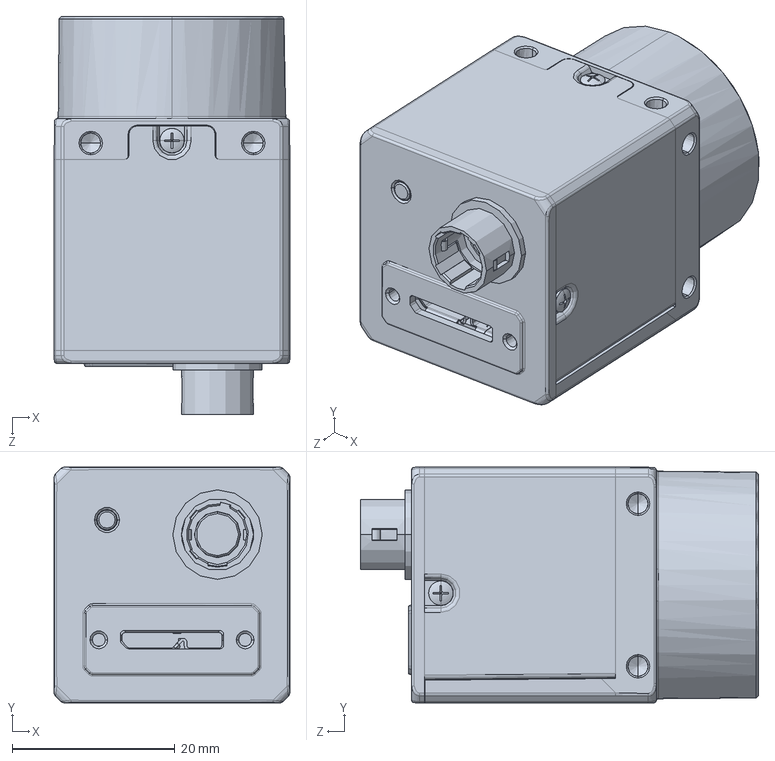
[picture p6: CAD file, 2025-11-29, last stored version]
2026_Vangaurd_Dart_Structure/飞镖(V2improved)/飞镖(V2)/官方件/深圳大学RobotPilots战队-哨兵机器人-标准件-海康CS016UC相机_.SLDPRT
29.0 x 29.0 x 49.0 mm

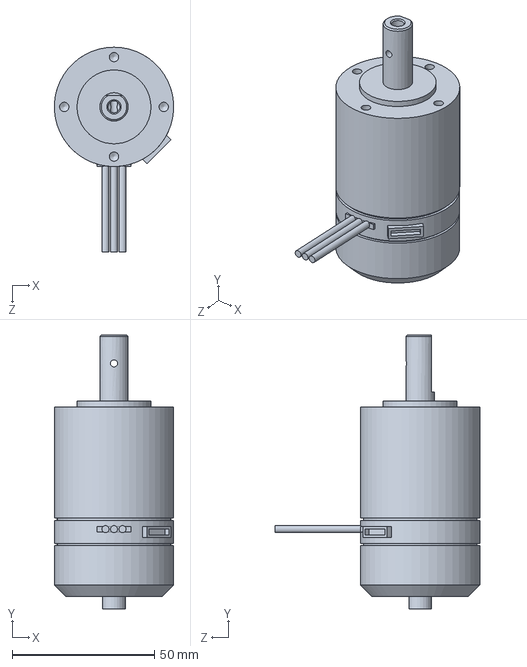
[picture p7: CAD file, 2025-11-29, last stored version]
2026_Vangaurd_Dart_Structure/飞镖(V2improved)/飞镖(V2)/平行换弹夹/M3508电机_.SLDPRT
42.0 x 96.4 x 72.0 mm

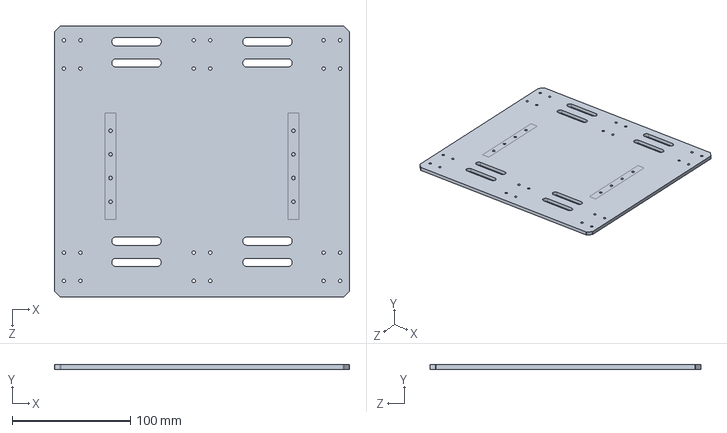
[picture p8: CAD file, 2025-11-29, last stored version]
2026_Vangaurd_Dart_Structure/飞镖(V2improved)/飞镖(V2)/总装/23RM飞镖04-01上层/23RM-飞镖04.01.0024摩擦轮安装板_.SLDPRT
250.0 x 4.00 x 230.0 mm

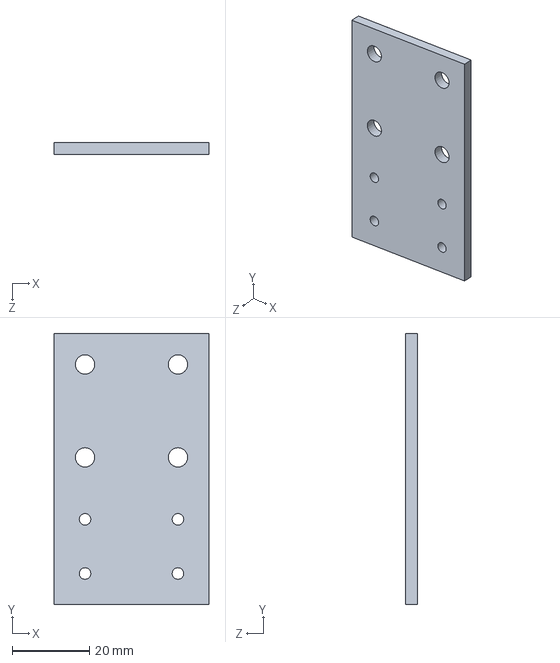
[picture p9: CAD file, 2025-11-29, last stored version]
2026_Vangaurd_Dart_Structure/飞镖(V2improved)/飞镖(V2)/总装/前连接板_.SLDPRT
40.0 x 70.0 x 3.00 mm

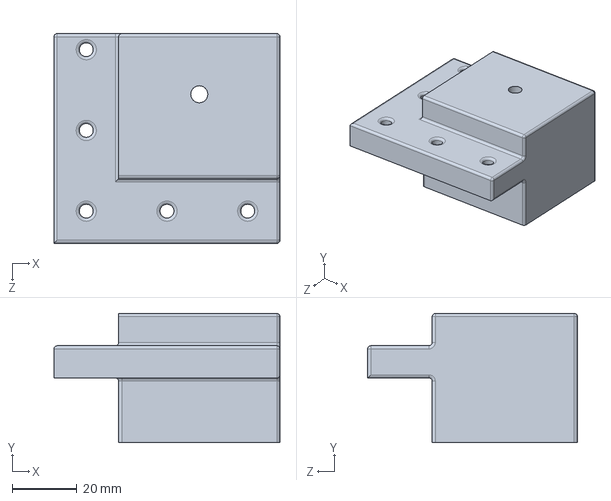
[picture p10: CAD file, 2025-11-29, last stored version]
2026_Vangaurd_Dart_Structure/飞镖(V2improved)/飞镖(V2)/总装/底座/磁吸座固定件2_.SLDPRT
70.0 x 40.0 x 65.0 mm

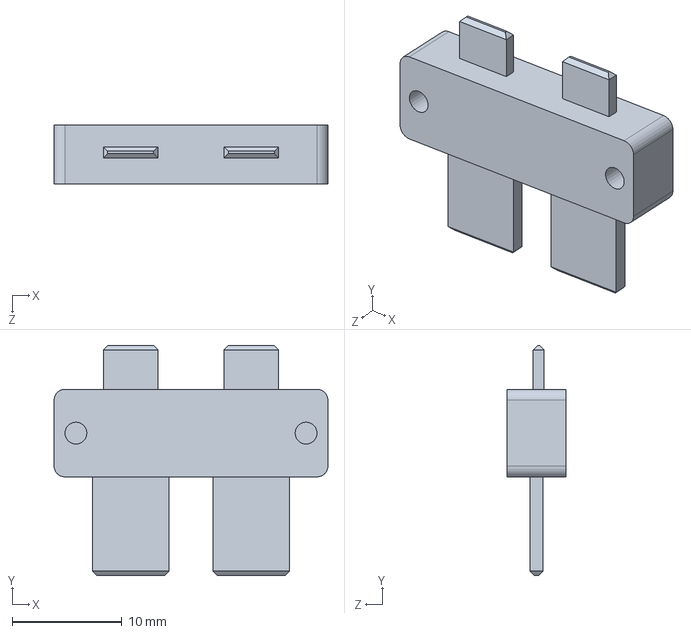
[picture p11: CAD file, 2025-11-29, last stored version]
2026_Vangaurd_Dart_Structure/飞镖(V2improved)/飞镖(V2)/总装/自制低成本轻量化电池架/电池架铜片-成品_.SLDPRT
25.0 x 21.0 x 5.40 mm

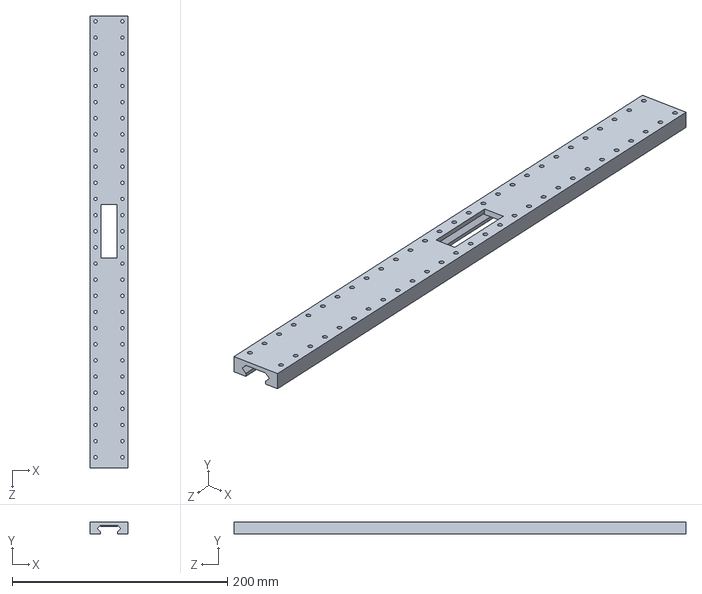
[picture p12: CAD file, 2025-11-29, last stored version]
2026_Vangaurd_Dart_Structure/飞镖(V2improved)/飞镖(V2)/打印件/装弹导轨槽(需切割).SLDPRT
35.0 x 11.1 x 420.0 mm

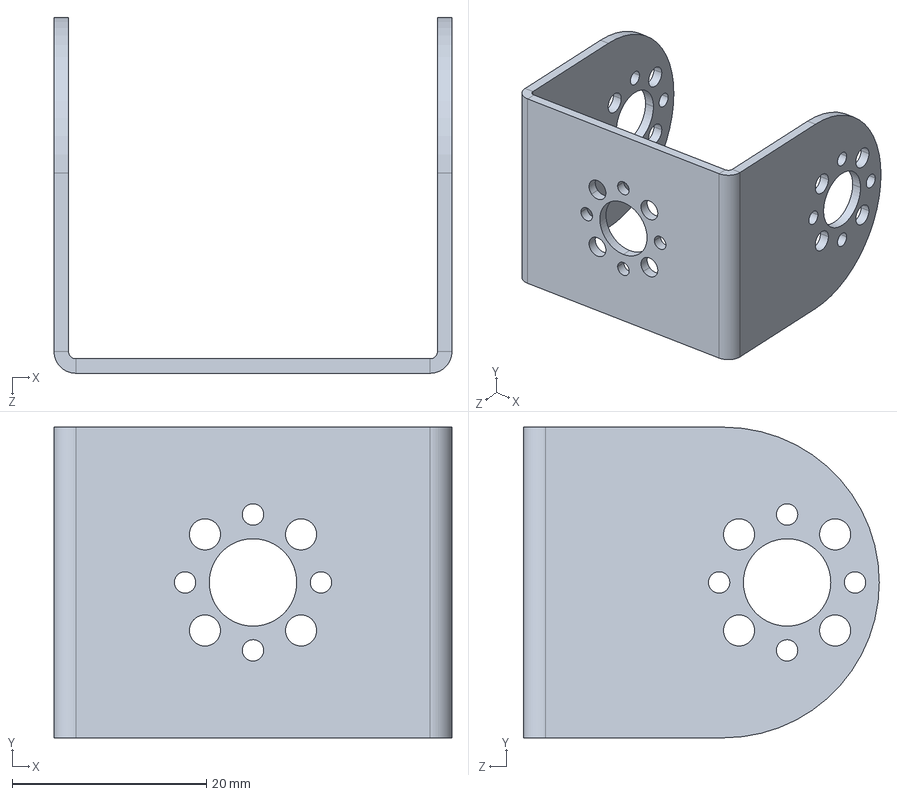
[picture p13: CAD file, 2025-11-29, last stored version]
2026_Vangaurd_Dart_Structure/飞镖(V2improved)/飞镖(V2)/换弹结构改进BOM/04 总线舵机相关图纸/HX-06L U型支架/HX-06L U型支架.STEP
41.0 x 32.0 x 36.6 mm

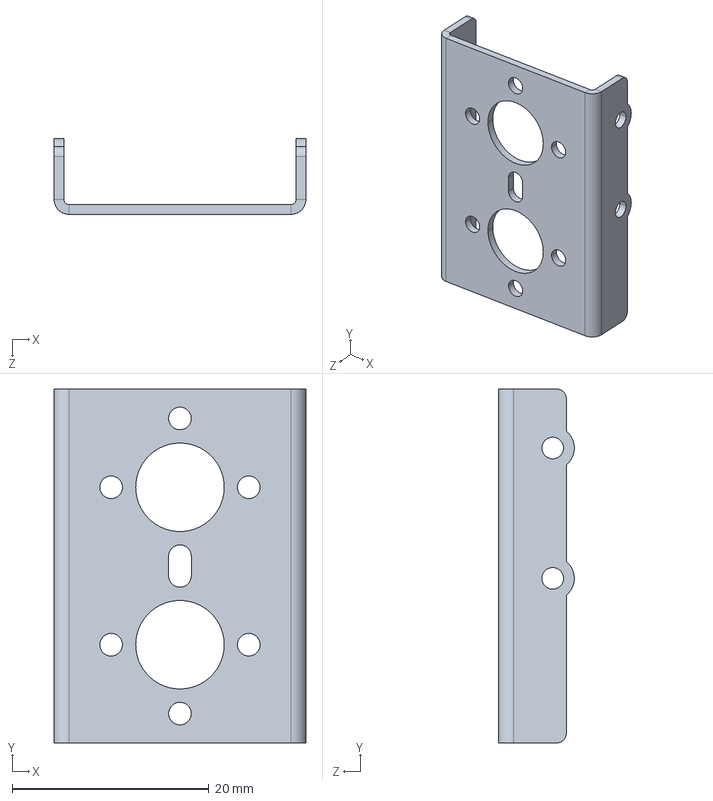
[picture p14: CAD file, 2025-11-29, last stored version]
2026_Vangaurd_Dart_Structure/飞镖(V2improved)/飞镖(V2)/换弹结构改进BOM/04 总线舵机相关图纸/HX-06L 侧面支架/HX-06L 侧面支架.STEP
25.6 x 36.0 x 7.70 mm

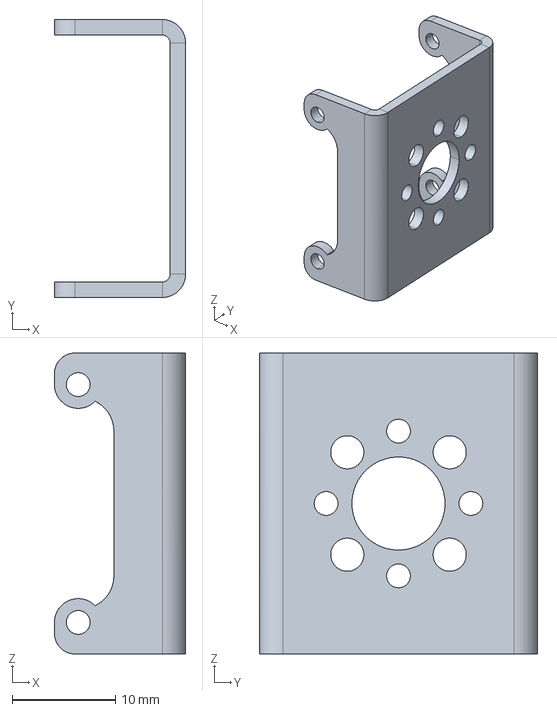
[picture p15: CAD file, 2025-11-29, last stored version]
2026_Vangaurd_Dart_Structure/飞镖(V2improved)/飞镖(V2)/换弹结构改进BOM/04 总线舵机相关图纸/HX-06L 底面支架/HX-06L 底面支架.STEP
12.7 x 26.9 x 29.1 mm

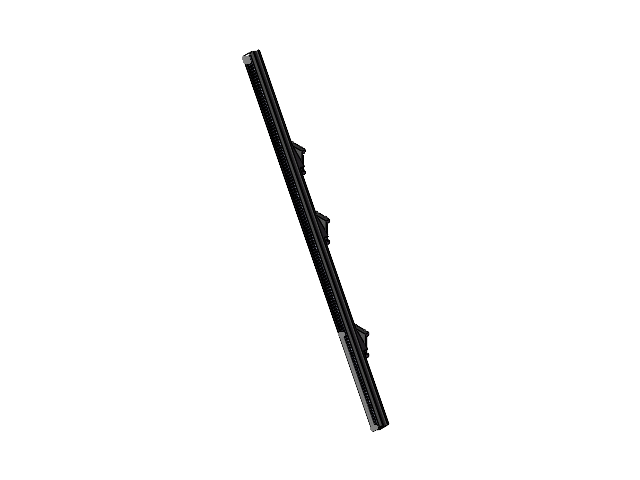
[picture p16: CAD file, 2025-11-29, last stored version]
2026_Vangaurd_Dart_Structure/飞镖(V2improved)/飞镖(V2)/测试(无用)/齿条+传动.SLDASM
装弹导轨_
齿条_

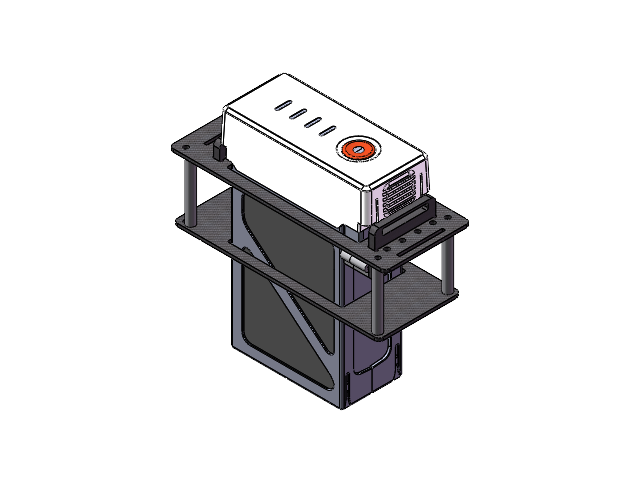
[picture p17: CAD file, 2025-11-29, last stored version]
2026_Vangaurd_Dart_Structure/飞镖(V2improved)/飞镖(V2)/总装/自制低成本轻量化电池架/自制低成本轻量化电池架总装_.SLDASM
轻量化电池架上板材
电池架卡口-铜片端
电池架卡扣
M3通用块6-6-40 x 2
电池架铜片-成品
电池架铜片固定机加件
电池架铜片机加件盖板可打印
TB48S电池
M3x40铝柱 x 4
轻量化电池架下板材

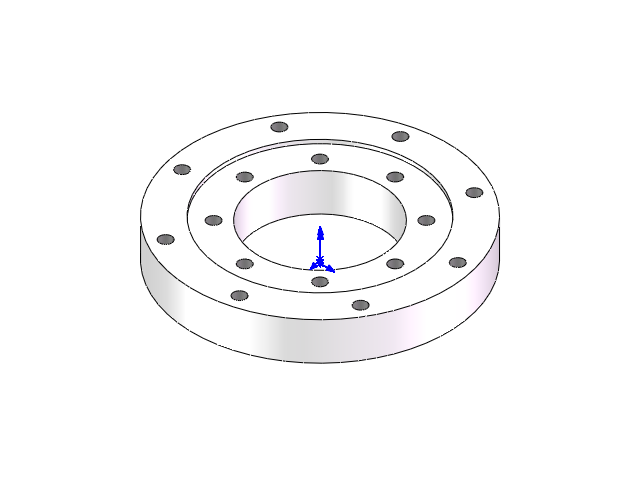
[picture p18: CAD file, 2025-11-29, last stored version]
2026_Vangaurd_Dart_Structure/飞镖(V2improved)/飞镖(V2)/总装/底座/23RM-飞镖04.02.0001回转支撑_.SLDASM
内环_
外环_

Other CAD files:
2026_Vangaurd_Dart_Structure/飞镖(V2improved)/飞镖(V2)/平行换弹夹/导弹v1.0.01225_.SLDASM
2026_Vangaurd_Dart_Structure/飞镖(V2improved)/飞镖(V2)/总装/底座/23RM-飞镖00.03.0004(电池组躺式)_.SLDASM
2026_Vangaurd_Dart_Structure/飞镖(V2improved)/飞镖(V2)/总装/发射机构/复件 镜向弹簧张紧铝方_.SLDPRT
2026_Vangaurd_Dart_Structure/飞镖(V2improved)/飞镖(V2)/换弹结构改进BOM/04 总线舵机相关图纸/HX-06L 舵机/brep_3_1.SLDPRT.SLDPRT
2026_Vangaurd_Dart_Structure/飞镖(V2improved)/飞镖(V2)/平行换弹夹/20X20方铝-换弹架用_.SLDPRT
2026_Vangaurd_Dart_Structure/飞镖(V2improved)/飞镖(V2)/平行换弹夹/3508换弹驱动座_.SLDPRT
2026_Vangaurd_Dart_Structure/飞镖(V2improved)/飞镖(V2)/平行换弹夹/RoboMaster飞镖触发头1225_.SLDPRT
2026_Vangaurd_Dart_Structure/飞镖(V2improved)/飞镖(V2)/平行换弹夹/压弹杆_.SLDPRT
2026_Vangaurd_Dart_Structure/飞镖(V2improved)/飞镖(V2)/平行换弹夹/圆柱齿轮60×1_.SLDPRT
2026_Vangaurd_Dart_Structure/飞镖(V2improved)/飞镖(V2)/平行换弹夹/导向垫片_.SLDPRT
2026_Vangaurd_Dart_Structure/飞镖(V2improved)/飞镖(V2)/平行换弹夹/尾翼1225_.SLDPRT
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

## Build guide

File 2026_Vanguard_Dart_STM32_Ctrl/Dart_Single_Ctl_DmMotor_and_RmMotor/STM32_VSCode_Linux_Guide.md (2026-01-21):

# Linux 下 STM32 VS Code 开发指南

本文档总结了在 Linux 环境下使用 **STM32 VS Code Extension** 进行开发的注意事项、通用配置模板以及 CMSIS-DAP 调试器的详细设置方法。

## 1. STM32 VS Code Extension 使用避坑指南

该插件核心是基于 **Cortex-Debug** 和 **CMake** 的封装。在 Linux 下使用时，建议遵循以下最佳实践以避免常见问题。

### A. 环境变量与路径
*   **问题**：插件默认倾向于使用 ST 官方的 `CubeCLT` 路径，可能无法识别 Linux 系统安装的工具。
*   **建议**：
    *   使用系统包管理器安装核心工具：`sudo apt install openocd gdb-multiarch`。
    *   在配置中**硬编码**系统路径（如 `/usr/bin/openocd`），比依赖插件的自动检测更稳定。

### B. 调试器选择 (OpenOCD vs ST-LINK)
*   **OpenOCD (推荐)**：
    *   支持多种调试器 (CMSIS-DAP, J-Link, ST-Link)。
    *   对 **Live Watch (实时变量监控)** 支持极佳。
*   **ST-LINK GDB Server**：
    *   ST 官方工具，对 ST-Link 固件支持好，但 Live Watch 功能往往不可用或不稳定。

### C. SVD 文件 (寄存器视图)
*   **作用**：让调试界面的 "Peripherals" 窗口显示芯片外设寄存器的具体值。
*   **操作**：建议下载对应芯片的 `.svd` 文件放入项目目录（如 `.vscode/` 下），并在 `launch.json` 中配置引用，确保项目移植性。

---

## 2. Linux 通用 `launch.json` 模板

将以下内容覆盖或合并到你的 `.vscode/launch.json`。此模板优化了路径配置，移除了对特定插件变量的过度依赖。

**使用前请修改标注 `TODO` 的部分** (如 `device`, `configFiles`, `svdFile`)。

```json
{
    "version": "0.2.0",
    "configurations": [
        /* ------------------------------------------------------------------
         * 配置 1: OpenOCD (推荐 - 通用性强，支持 Live Watch)
         * 适用于: CMSIS-DAP, ST-Link, J-Link
         * ------------------------------------------------------------------ */
        {
            "name": "Linux - OpenOCD (Universal)",
            "cwd": "${workspaceFolder}",
            "type": "cortex-debug",
            "request": "launch",
            "servertype": "openocd",
            
            // 自动获取 CMake 生成的 ELF 文件路径
            "executable": "${command:cmake.launchTargetPath}",
            
            // TODO: 修改为你的具体芯片型号
            "device": "STM32F427IIHx", 
            
            // Linux 系统 OpenOCD 默认路径
            "serverpath": "/usr/bin/openocd",
            
            // TODO: 根据调试器和芯片修改
            // 接口: interface/cmsis-dap.cfg (DAP-Link), interface/stlink.cfg (ST-Link)
            // 目标: target/stm32f4x.cfg (F4系列), target/stm32f1x.cfg (F1系列)
            "configFiles": [
                "interface/cmsis-dap.cfg", 
                "target/stm32f4x.cfg"
            ],

            // 开启实时变量监控 (无需暂停核心即可看变量变化)
            "liveWatch": {
                "enabled": true,
                "samplesPerSecond": 4
            },

            // TODO: 指定 SVD 文件路径
            "svdFile": "${workspaceFolder}/.vscode/STM32F427.svd", 
            
            "runToEntryPoint": "main",
            "showDevDebugOutput": "none",
            "gdbPath": "gdb-multiarch" 
        },

        /* ------------------------------------------------------------------
         * 配置 2: ST-Link GDB Server (官方原生)
         * 适用于: 仅限 ST-Link 调试器
         * ------------------------------------------------------------------ */
        {
            "name": "Linux - ST-Link Official",
            "cwd": "${workspaceFolder}",
            "type": "cortex-debug",
            "request": "launch",
            "servertype": "stlink",
            "executable": "${command:cmake.launchTargetPath}",
            "device": "STM32F427IIHx",
            "interface": "swd",
            "serverpath": "ST-LINK_gdbserver", // 需确保在 PATH 中或写绝对路径
            "stm32cubeprogrammer": "STM32_Programmer_CLI",
            "runToEntryPoint": "main",
            "svdFile": "${workspaceFolder}/.vscode/STM32F427.svd",
            "gdbPath": "gdb-multiarch",
            "serverArgs": ["-m", "0"]
        }
    ]
}
```

---

## 3. CMSIS-DAP Link 配置指南

CMSIS-DAP 是一种通用的开源调试协议，无需专有驱动，配合 OpenOCD 使用效果极佳。

### 3.1 硬件连接 (SWD)

| CMSIS-DAP 引脚 | STM32 引脚 | 备注 |
| :--- | :--- | :--- |
| **SWCLK** | **SWCLK (PA14)** | 时钟 |
| **SWDIO** | **SWDIO (PA13)** | 数据 |
| **GND** | **GND** | **必须共地** |
| **3V3** | **3V3** | 仅当需要调试器供电时连接 |

### 3.2 Linux 权限配置 (udev rules)

为了让非 root 用户（VS Code）能访问 USB 调试器，必须配置 udev 规则。

1.  **创建规则文件**:
    ```bash
    sudo nano /etc/udev/rules.d/99-cmsis-dap.rules
    ```

2.  **写入以下内容**:
    ```bash
    # CMSIS-DAP compatible adapters
    SUBSYSTEM=="usb", ATTR{idVendor}=="0d28", ATTR{idProduct}=="0204", MODE="0666"
    SUBSYSTEM=="usb", KERNEL=="hidraw*", ATTRS{idVendor}=="0d28", ATTRS{idProduct}=="0204", MODE="0666"
    SUBSYSTEM=="usb", ATTRS{product}=="*CMSIS-DAP*", MODE="0666"
    ```

3.  **重载并生效**:
    ```bash
    sudo udevadm control --reload-rules
    sudo udevadm trigger
    ```
    *提示：执行后请重新插拔调试器。*

### 3.3 验证连接

在终端运行以下 OpenOCD 命令测试连接（以 STM32F4 为例）：

```bash
openocd -f interface/cmsis-dap.cfg -f target/stm32f4x.cfg
```

*   **成功**: 输出包含 `Info : STM32F4xx flash size is ...`。
*   **失败**: 提示 `Error: open failed` (检查权限) 或 `target not found` (检查接线)。

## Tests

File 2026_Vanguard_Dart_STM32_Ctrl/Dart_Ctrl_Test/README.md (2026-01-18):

# STM32 飞镖控制系统 (Vanguard Dart)

## 项目概述
本系统是基于 STM32F427IIH 开发的飞镖机器人控制系统。该系统集成了多电机协同控制、高精度传感器反馈、多协议串口通信以及基于 FreeRTOS 的实时任务调度，旨在 15 秒内高效完成 4 次飞镖发射过程。

---

## 核心技术栈
- **硬件平台**: STM32F427IIH (A板)
- **实时系统**: FreeRTOS
- **驱动库**: STM32 HAL, DSP Library
- **通信协议**: CAN (1Mbps), UART (DMA+环形缓冲区), IBUS (遥控器), 总线舵机协议
- **控制算法**: 增量式/位置式 PID, 面向对象电机驱动框架

---

## 文档索引

### 1. 开发指南
- [**快速开始**](#快速开始) - 环境配置与系统初始化流程。
- [**系统架构**](#系统架构) - 任务调度与模块间的交互逻辑。
- [**开发规范**](Docs/README.md#开发规范) - 结构体对齐、命名及协议扩展建议。

### 2. 模块技术文档
- [**BSP_UART使用说明**](Docs/BSP_UART使用说明.md) - **[重点]** 环形缓冲区、多协议状态机与三层通信架构。
- [**CanMotor使用说明**](Docs/CanMotor使用说明.md) - **[核心]** 统一电机管理框架 (支持 RM 3508/2006, DM 4310/3519)。
- [**BSP_CAN使用说明**](Docs/BSP_CAN使用说明.md) - CAN 总线过滤器配置与多电机 ID 管理。
- [**HX06L舵机使用说明**](Docs/HX06L舵机使用说明.md) - 总线舵机控制协议与多舵机协同。
- [**BSP_DWT使用说明**](Docs/BSP_DWT使用说明.md) - 高精度计时（微秒级）与性能分析工具。

---

## 系统架构

系统通过任务间的同步与互斥，实现了从换弹、储能到发射的闭环流程。

### 硬件拓扑与数据流
```text
                                [ 外部输入 ]
                                     |
    +--------------------------------+--------------------------------+
    |                                |                                |
[ 遥控器 IA6B ]                  [ 视觉/上位机 ]                  [ 传感器反馈 ]
    | (IBUS)                         | (UART)                         |
    V                                V                                V
+--------------------------------------------------------------------------+
|                          串口协议解析层 (UartModule)                        |
+--------------------------------------------------------------------------+
                                     |
                                     V
+--------------------------------------------------------------------------+
|                          FreeRTOS 任务调度层                               |
|  +--------------+      +--------------+      +--------------+           |
|  |   换弹任务   | <--> |   储能任务   | <--> |   发射任务   |           |
|  | (RM3508/舵机)|      | (DM3519*2)   |      | (PWM/MG996R) |           |
|  +--------------+      +--------------+      +--------------+           |
+--------------------------------------------------------------------------+
                                     | (PID计算 / 指令下发)
                                     V
+--------------------------------------------------------------------------+
|                          硬件抽象层 (BSP_CAN/UART)                          |
+--------------------------------------------------------------------------+
```

### 任务逻辑流
1. **StateSetTask**: 初始化云台 Yaw 轴 (DM4310) 和扳机射程 (RM2006) 至预设位置。
2. **StoreEnergyTask**: 控制左右 DM3519 电机将拉簧拉至指定动能位置，利用互斥量与换弹任务同步。
3. **LoadTask**: 协同 RM3508 传送带电机与总线舵机，将飞镖精准推送到发射位。
4. **ShootTask**: 触发 MG996R 舵机释放扳机，完成发射。

---

## 快速开始

### 1. 系统初始化
在 `main.c` 中，系统按序启动硬件与内核：
```c
int main(void) {
    HAL_Init();
    SystemClock_Config();
    
    // 1. 初始化高精度计时器 (180MHz)
    DWT_Init(180); 
    
    // 2. 初始化底层外设与电源管理
    BSP_POWER_Init(); // 开启 24V 使能
    BSP_UART_Init(); 
    MotorInit(); 
    CanFilterCfg();
    
    // 3. 启动应用层任务初始化
    TaskInitFunc();
    
    // 4. 进入 RTOS 调度
    osKernelStart();
}
```

### 2. 电机控制 (OOP 示例)
```c
// 获取电机句柄并下发 MIT 模式指令
MotorTypeDef *yaw = Motor_GetHandle(DM_4310_YAW);
DM_Motor_SetMITParams(yaw, target_pos, target_vel, kp, kd, torque);
DM_Motor_SendControl(yaw);
```

### 3. 总线舵机控制
```c
// 驱动 0x01 号舵机在 500ms 内转动到 500 位置
serial_servo_set_position(&serial_servo_controller, 0x01, 500, 500);
```

---

## 核心配置速查

- **CAN 波特率**: 1Mbps (CAN1/CAN2)
- **UART 波特率**: 115200 (上位机), 115200 (总线舵机), 115200 (IA6B)
- **电机 ID 分配**:
  - **RM-M3508 (换弹)**: 0x201
  - **RM-M2006 (扳机)**: 0x205
  - **DM-J4310 (Yaw)**: 0x003 (MIT 模式)
  - **DM-S3519 (储能)**: 0x001 (左), 0x002 (右)
- **总线舵机 ID**: 0x01, 0x02, 0x03 (换弹机构)

---

## 开发规范

1. **协议安全**: 所有通信数据帧建议在 `UartProtocol.c` 中通过状态机解析，严禁在中断中进行复杂逻辑处理。
2. **电机安全**: 调试时请务必配置 `config.h` 中的 `SOFT_LIMIT` 参数，防止堵转损坏机构。
3. **实时性**: 任务优先级按 `osPriorityNormal` (发射) > `osPriorityBelowNormal` (换弹) 分配，确保紧急控制响应。

---
**维护者**: 邓金水 / Vanguard Team  
**最后更新**: 2026-01-18

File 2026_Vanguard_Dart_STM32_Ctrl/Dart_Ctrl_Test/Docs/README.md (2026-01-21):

# STM32 飞镖控制系统 (Vanguard Dart)

## 项目概述
本系统是基于 STM32F427IIH 开发的飞镖机器人控制系统。该系统集成了多电机协同控制、高精度传感器反馈、多协议串口通信以及基于 FreeRTOS 的实时任务调度，旨在 15 秒内高效完成 4 次飞镖发射过程。

---

## 核心技术栈
- **硬件平台**: STM32F427IIH (A板)
- **实时系统**: FreeRTOS
- **驱动库**: STM32 HAL, DSP Library
- **通信协议**: CAN (1Mbps), UART (DMA+环形缓冲区), IBUS (遥控器), 总线舵机协议
- **控制算法**: 增量式/位置式 PID, 面向对象电机驱动框架

---

## 文档索引

### 1. 开发指南
- [**快速开始**](#快速开始) - 环境配置与系统初始化流程。
- [**系统架构**](#系统架构) - 任务调度与模块间的交互逻辑。
- [**开发规范**](README.md#开发规范) - 结构体对齐、命名及协议扩展建议。

### 2. 模块技术文档
- [**BSP_UART使用说明**](BSP_UART使用说明.md) - **[重点]** 环形缓冲区、多协议状态机与三层通信架构。
- [**CanMotor使用说明**](CanMotor使用说明.md) - **[核心]** 统一电机管理框架 (支持 RM 3508/2006, DM 4310/3519)。
- [**BSP_CAN使用说明**](BSP_CAN使用说明.md) - CAN 总线过滤器配置与多电机 ID 管理。
- [**HX06L舵机使用说明**](HX06L舵机使用说明.md) - 总线舵机控制协议与多舵机协同。
- [**BSP_DWT使用说明**](BSP_DWT使用说明.md) - 高精度计时（微秒级）与性能分析工具。

---

## 系统架构

系统通过任务间的同步与互斥，实现了从换弹、储能到发射的闭环流程。

### 硬件拓扑与数据流
```text
                                [ 外部输入 ]
                                     |
    +--------------------------------+--------------------------------+
    |                                |                                |
[ 遥控器 IA6B ]                  [ 视觉/上位机 ]                  [ 传感器反馈 ]
    | (IBUS)                         | (UART)                         |
    V                                V                                V
+--------------------------------------------------------------------------+
|                          串口协议解析层 (UartModule)                        |
+--------------------------------------------------------------------------+
                                     |
                                     V
+--------------------------------------------------------------------------+
|                          FreeRTOS 任务调度层                               |
|  +--------------+      +--------------+      +--------------+           |
|  |   换弹任务   | <--> |   储能任务   | <--> |   发射任务   |           |
|  | (RM3508/舵机)|      | (DM3519*2)   |      | (PWM/MG996R) |           |
|  +--------------+      +--------------+      +--------------+           |
+--------------------------------------------------------------------------+
                                     | (PID计算 / 指令下发)
                                     V
+--------------------------------------------------------------------------+
|                          硬件抽象层 (BSP_CAN/UART)                          |
+--------------------------------------------------------------------------+
```

### 任务逻辑流
1. **StateSetTask**: 初始化云台 Yaw 轴 (DM4310) 和扳机射程 (RM2006) 至预设位置。
2. **StoreEnergyTask**: 控制左右 DM3519 电机将拉簧拉至指定动能位置，利用互斥量与换弹任务同步。
3. **LoadTask**: 协同 RM3508 传送带电机与总线舵机，将飞镖精准推送到发射位。
4. **ShootTask**: 触发 MG996R 舵机释放扳机，完成发射。

---

## 快速开始

### 1. 系统初始化
在 `main.c` 中，系统按序启动硬件与内核：
```c
int main(void) {
    HAL_Init();
    SystemClock_Config();
    
    // 1. 初始化高精度计时器 (180MHz)
    DWT_Init(180); 
    
    // 2. 初始化底层外设与电源管理
    BSP_POWER_Init(); // 开启 24V 使能
    BSP_UART_Init(); 
    MotorInit(); 
    CanFilterCfg();
    
    // 3. 启动应用层任务初始化
    TaskInitFunc();
    
    // 4. 进入 RTOS 调度
    osKernelStart();
}
```

### 2. 电机控制 (OOP 示例)
```c
// 获取电机句柄并下发 MIT 模式指令
MotorTypeDef *yaw = Motor_GetHandle(DM_4310_YAW);
DM_Motor_SetMITParams(yaw, target_pos, target_vel, kp, kd, torque);
DM_Motor_SendControl(yaw);
```

### 3. 总线舵机控制
```c
// 驱动 0x01 号舵机在 500ms 内转动到 500 位置
serial_servo_set_position(&serial_servo_controller, 0x01, 500, 500);
```

---

## 核心配置速查

- **CAN 波特率**: 1Mbps (CAN1/CAN2)
- **UART 波特率**: 115200 (上位机), 115200 (总线舵机), 115200 (IA6B)
- **电机 ID 分配**:
  - **RM-M3508 (换弹)**: 0x201
  - **RM-M2006 (扳机)**: 0x205
  - **DM-J4310 (Yaw)**: TX=0x003, RX=0x013 (MIT 模式, motor_id=3)
  - **DM-S3519 (储能左)**: TX=0x101, RX=0x021 (位置速度模式, motor_id=1)
  - **DM-S3519 (储能右)**: TX=0x102, RX=0x022 (位置速度模式, motor_id=2)
- **总线舵机 ID**: 0x01, 0x02, 0x03 (换弹机构)

---

## 开发规范

1. **协议安全**: 所有通信数据帧建议在 `UartProtocol.c` 中通过状态机解析，严禁在中断中进行复杂逻辑处理。
2. **电机安全**: 调试时请务必配置 `config.h` 中的 `SOFT_LIMIT` 参数，防止堵转损坏机构。
3. **实时性**: 任务优先级按 `osPriorityNormal` (发射) > `osPriorityBelowNormal` (换弹) 分配，确保紧急控制响应。

---
**维护者**: 邓金水 / Vanguard Team  
**最后更新**: 2026-01-21# STM32 飞镖控制系统 (Vanguard Dart)

## 项目概述
本系统是基于 STM32F427IIH 开发的飞镖机器人控制系统。该系统集成了多电机协同控制、高精度传感器反馈、多协议串口通信以及基于 FreeRTOS 的实时任务调度，旨在 15 秒内高效完成 4 次飞镖发射过程。

---

## 核心技术栈
- **硬件平台**: STM32F427IIH (A板)
- **实时系统**: FreeRTOS
- **驱动库**: STM32 HAL, DSP Library
- **通信协议**: CAN (1Mbps), UART (DMA+环形缓冲区), IBUS (遥控器), 总线舵机协议
- **控制算法**: 增量式/位置式 PID, 面向对象电机驱动框架

---

## 文档索引

### 1. 开发指南
- [**快速开始**](#快速开始) - 环境配置与系统初始化流程。
- [**系统架构**](#系统架构) - 任务调度与模块间的交互逻辑。
- [**开发规范**](README.md#开发规范) - 结构体对齐、命名及协议扩展建议。

### 2. 模块技术文档
- [**BSP_UART使用说明**](BSP_UART使用说明.md) - **[重点]** 环形缓冲区、多协议状态机与三层通信架构。
- [**CanMotor使用说明**](CanMotor使用说明.md) - **[核心]** 统一电机管理框架 (支持 RM 3508/2006, DM 4310/3519)。
- [**BSP_CAN使用说明**](BSP_CAN使用说明.md) - CAN 总线过滤器配置与多电机 ID 管理。
- [**HX06L舵机使用说明**](HX06L舵机使用说明.md) - 总线舵机控制协议与多舵机协同。
- [**BSP_DWT使用说明**](BSP_DWT使用说明.md) - 高精度计时（微秒级）与性能分析工具。

---

## 系统架构

系统通过任务间的同步与互斥，实现了从换弹、储能到发射的闭环流程。

### 硬件拓扑与数据流
```text
                                [ 外部输入 ]
                                     |
    +--------------------------------+--------------------------------+
    |                                |                                |
[ 遥控器 IA6B ]                  [ 视觉/上位机 ]                  [ 传感器反馈 ]
    | (IBUS)                         | (UART)                         |
    V                                V                                V
+--------------------------------------------------------------------------+
|                          串口协议解析层 (UartModule)                        |
+--------------------------------------------------------------------------+
                                     |
                                     V
+--------------------------------------------------------------------------+
|                          FreeRTOS 任务调度层                               |
|  +--------------+      +--------------+      +--------------+           |
|  |   换弹任务   | <--> |   储能任务   | <--> |   发射任务   |           |
|  | (RM3508/舵机)|      | (DM3519*2)   |      | (PWM/MG996R) |           |
|  +--------------+      +--------------+      +--------------+           |
+--------------------------------------------------------------------------+
                                     | (PID计算 / 指令下发)
                                     V
+--------------------------------------------------------------------------+
|                          硬件抽象层 (BSP_CAN/UART)                          |
+--------------------------------------------------------------------------+
```

### 任务逻辑流
1. **StateSetTask**: 初始化云台 Yaw 轴 (DM4310) 和扳机射程 (RM2006) 至预设位置。
2. **StoreEnergyTask**: 控制左右 DM3519 电机将拉簧拉至指定动能位置，利用互斥量与换弹任务同步。
3. **LoadTask**: 协同 RM3508 传送带电机与总线舵机，将飞镖精准推送到发射位。
4. **ShootTask**: 触发 MG996R 舵机释放扳机，完成发射。

---

## 快速开始

### 1. 系统初始化
在 `main.c` 中，系统按序启动硬件与内核：
```c
int main(void) {
    HAL_Init();
    SystemClock_Config();
    
    // 1. 初始化高精度计时器 (180MHz)
    DWT_Init(180); 
    
    // 2. 初始化底层外设与电源管理
    BSP_POWER_Init(); // 开启 24V 使能
    BSP_UART_Init(); 
    MotorInit(); 
    CanFilterCfg();
    
    // 3. 启动应用层任务初始化
    TaskInitFunc();
    
    // 4. 进入 RTOS 调度
    osKernelStart();
}
```

### 2. 电机控制 (OOP 示例)
```c
// 获取电机句柄并下发 MIT 模式指令
MotorTypeDef *yaw = Motor_GetHandle(DM_4310_YAW);
DM_Motor_SetMITParams(yaw, target_pos, target_vel, kp, kd, torque);
DM_Motor_SendControl(yaw);
```

### 3. 总线舵机控制
```c
// 驱动 0x01 号舵机在 500ms 内转动到 500 位置
serial_servo_set_position(&serial_servo_controller, 0x01, 500, 500);
```

---

## 核心配置速查

- **CAN 波特率**: 1Mbps (CAN1/CAN2)
- **UART 波特率**: 115200 (上位机), 115200 (总线舵机), 115200 (IA6B)
- **电机 ID 分配**:
  - **RM-M3508 (换弹)**: 0x201
  - **RM-M2006 (扳机)**: 0x205
  - **DM-J4310 (Yaw)**: TX=0x003, RX=0x013 (MIT 模式, motor_id=3)
  - **DM-S3519 (储能左)**: TX=0x101, RX=0x021 (位置速度模式, motor_id=1)
  - **DM-S3519 (储能右)**: TX=0x102, RX=0x022 (位置速度模式, motor_id=2)
- **总线舵机 ID**: 0x01, 0x02, 0x03 (换弹机构)

---

## 开发规范

1. **协议安全**: 所有通信数据帧建议在 `UartProtocol.c` 中通过状态机解析，严禁在中断中进行复杂逻辑处理。
2. **电机安全**: 调试时请务必配置 `config.h` 中的 `SOFT_LIMIT` 参数，防止堵转损坏机构。
3. **实时性**: 任务优先级按 `osPriorityNormal` (发射) > `osPriorityBelowNormal` (换弹) 分配，确保紧急控制响应。

---
**维护者**: 邓金水 / Vanguard Team  
**最后更新**: 2026-01-21

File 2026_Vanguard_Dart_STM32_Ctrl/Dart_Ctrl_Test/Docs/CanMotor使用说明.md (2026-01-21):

# CanMotor 使用说明文档

## 文件信息
- **头文件**: `User/inc/CanMotor.h`
- **源文件**: `User/src/CanMotor.c`
- **作用**: CAN电机统一管理层(支持RM电机和DM电机)

---

## 功能概述

CanMotor是电机管理的核心模块，负责统一管理RM电机和DM电机，引入了硬件抽象层(HAL)和面向对象(OO)的设计思想，提供了高度解耦和易于扩展的电机管理机制。

### 2026-01-17 性能优化
- **数据展平**: 高频参数(减速比、ID等)直接存储在实例中，减少3层寻址开销。
- **快速分发**: 中断回调使用展平后的ID直接匹配，提升响应速度。

---

## 重要宏定义

```c
#define CtrlMotorLen 8           // 电机控制报文长度(默认8字节)
#define g_CanMotorNum 5          // CAN电机总数量 (定义在 bsp_can.h)
```

---

## 数据结构

### MotorTypeDef 电机结构体 (核心)
```c
typedef struct _MotorTypeDef {
    // ==================== 快速访问区 (展平数据 - 优化点) ====================
    uint8_t MotorID;              // 电机ID
    can_motor_band band;          // 电机品牌
    can_motor_model model;        // 电机型号
    uint16_t can_id_tx;           // CAN发送ID (直接访问)
    uint16_t can_id_rx;           // CAN接收ID (即原 CAN_Rid)
    float gear_ratio;             // 减速比 (直接从类拷贝)
    float current_ratio;          // 电流/力矩转换系数
    int16_t max_current;          // 最大电流/限幅值

    // ==================== 原始存储区与反馈 ====================
    motor_inf MotorInf;                           // 电机品牌与型号
    uint8_t ReceiveMotorData[8];                  // 接收数据缓冲
    CAN_TxHeaderTypeDef g_TxHeader;               // CAN发送报文头
    MotorSolvedData_t motor_data;                 // 电机解算数据
    MotorConfig_t config;                         // 用户可调配置
    MotorParams_t params;                         // 电机固有参数

    // ==================== 面向对象扩展 ====================
    union {
        const struct _RM_MotorClass *rm_motor_class;
        const struct _DM_MotorClass *dm_motor_class;
    } motor_class;

    // ==================== 兼容性接口 (保留旧代码) ====================
    uint8_t (*SendMotorControl)(struct _MotorTypeDef *st);
    void (*calculate)(struct _MotorTypeDef *self);

    // PID控制器
    PID_t inner_pid;                              // 内环PID
    CASCADE_PID_t cascade_pid;                    // 串级PID
    uint16_t CAN_Rid;                             // 接收ID (兼容旧接口)
} MotorTypeDef;
```

---

## 核心API函数

### 1. 系统初始化与注册
- `MotorInit()`: 总初始化函数
- `MotorRegister()`: 注册所有电机
- `CanFilterCfg()`: 配置CAN过滤器（修正了拼写错误 Filter）

### 2. 电机句柄获取 (内联函数)
- `Motor_GetHandle(motor_id)`: 获取电机指针（带检查）
- `Motor_GetHandleFast(motor_id)`: 获取电机指针（最高性能）

### 3. 数据读取接口
- `Motor_GetTotalAngle(motor_id)`: 获取累计角度(°)
- `Motor_GetSpeedRPM(motor_id)`: 获取速度(rpm)
- `Motor_GetCurrent(motor_id)`: 获取电流(A)或力矩(N·m)

---

## DM电机ID配置表

### 2026-01-21 新增：集中式ID管理

DM电机的CAN ID现在通过配置表集中管理，修改ID只需修改一处。

#### 配置结构体
```c
typedef struct {
    uint8_t  motor_id;      // 达妙上位机设置的电机ID (0-15)
    uint16_t tx_id;         // 发送CAN ID
    uint16_t rx_id;         // 接收CAN ID
    DM_WorkMode work_mode;  // 工作模式
} DM_MotorIdConfig_t;
```

#### 当前ID配置 (`DM_Motor.c`)
```c
static const DM_MotorIdConfig_t g_DM_IdTable[] = {
    [DM_3519_STRENTH_LEFT]  = {1, 0x101, 0x021, DM_LOCATION_SPEED},
    [DM_3519_STRENTH_RIGHT] = {2, 0x102, 0x022, DM_LOCATION_SPEED},
    [DM_4310_YAW]           = {3, 0x003, 0x013, DM_MIT},
};
```

#### ID计算规则（供参考）
| 模式 | 发送ID | 接收ID |
|---|---|---|
| MIT | `0x000 + motor_id` | `0x010 + motor_id` |
| 位置速度 | `0x100 + motor_id` | `0x020 + motor_id` |
| 速度 | `0x200 + motor_id` | `0x030 + motor_id` |

#### 新建DM电机步骤
1. **CanMotor.h**: 在 `can_motor_cfg` 枚举中添加新电机
2. **DM_Motor.c**: 在 `g_DM_IdTable[]` 中添加ID配置
3. **DM_Motor.c**: 修改 `DM_GetIdConfig()` 范围检查
4. **CanMotor.c**: 在 `MotorRegister()` 中注册电机
5. **CanMotor.h**: 确保 `g_CanMotorNum` 足够

---

## 更新日志

- **2026-01-21**:
  - 新增DM电机ID配置表，集中管理所有DM电机CAN ID
  - 添加 `DM_MotorIdConfig_t` 结构体和 `DM_GetIdConfig()` 函数
- **2026-01-17**: 
  - 实施数据展平架构优化。
  - 优化中断分发逻辑。
  - 修正全局 `Filter` 拼写错误。
- **2026-01-03**: 
  - 引入硬件抽象层(HAL)支持
  - 新增面向对象(OO)类结构体设计

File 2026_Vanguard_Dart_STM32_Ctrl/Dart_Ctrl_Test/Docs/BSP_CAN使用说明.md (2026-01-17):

# BSP_CAN 使用说明文档

## 文件信息
- **头文件**: `Bsp/inc/bsp_can.h`
- **源文件**: `Bsp/src/bsp_can.c`
- **作用**: CAN总线通信的底层硬件抽象层(BSP)

---

## 核心API函数 (2026-01-17 更新)

### 1. CAN_Init()
初始化CAN外设及基础过滤器。

### 2. CAN_SendData()
发送8字节CAN数据帧。

### 3. FilterIdCfg_Init()
**注意**: 已统一修正拼写（原为 FliterIdCfg_Init）。
配置CAN过滤器ID掩码模式。

---

## 接收机制

本工程使用中断接收模式。底层 `stm32f4xx_it.c` 调用 `HAL_CAN_RxFifoXMsgPendingCallback`，随后分发至 `CanMotor.c` 中的 `CAN_FIFO_CBKHANDLER`。

---

## 更新日志
- **2026-01-17**: 修正全局 `Filter` 拼写错误，优化了过滤器配置接口的命名一致性。

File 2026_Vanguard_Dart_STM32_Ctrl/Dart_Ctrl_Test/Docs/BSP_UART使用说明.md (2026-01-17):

# UART 模块使用说明文档

## 架构概述

UART通信模块采用三层分离架构，确保底层驱动、协议解析和应用层接口的高度解耦：

```
┌─────────────────────────────────────────────┐
│            用户应用层 (UserTask.c 等)        │
└───────────────────────┬─────────────────────┘
                        ↓
┌─────────────────────────────────────────────┐
│     UartModule.c - 用户级数据包收发API       │
│   (User/src/UartModule.c)                   │
└───────────────────────┬─────────────────────┘
                        ↓
┌─────────────────────────────────────────────┐
│     UartProtocol.c - 协议解析逻辑与状态机    │
│   (Bsp/src/UartProtocol.c)                  │
└───────────────────────┬─────────────────────┘
                        ↓
┌─────────────────────────────────────────────┐
│     bsp_uart.c - 底层硬件驱动与环形缓冲区    │
│   (Bsp/src/bsp_uart.c)                      │
└─────────────────────────────────────────────┘
```

---

## 文件信息

| 层次 | 头文件 | 源文件 | 职责 |
|---|---|---|---|
| 用户层 | `User/inc/UartModule.h` | `User/src/UartModule.c` | 提供面向数据包的收发API、协议切换 |
| 协议层 | `Bsp/inc/UartProtocol.h` | `Bsp/src/UartProtocol.c` | 协议解析与校验（舵机协议、IBUS协议） |
| 驱动层 | `Bsp/inc/bsp_uart.h` | `Bsp/src/bsp_uart.c` | 硬件中断处理、环形发送/接收缓冲区管理 |

---

## 重要设计特性

### 1. 环形缓冲区与IBUS DMA
舵机协议使用环形缓冲区进行字节接收与解析；IBUS 协议由 UART6 通过 DMA 固定长度（32字节）接收并在中断中校验帧头和校验尾。
- **简化解析**: 舵机协议按字节状态机解析；IBUS 仅校验帧头与 16 位校验尾。
- **数据隔离**: IBUS 数据不会写入舵机环形缓冲区，避免协议耦合。

### 2. 多协议状态机
支持三种协议类型的实时解析：
- `PROTOCOL_SERVO_MCU`: 舵机控制板协议（0x55 0x55开头，无CRC）。
- `PROTOCOL_SERVO_NO_MCU`: 舵机驱动板直接协议（0x55 0x55开头，有CRC）。
- `PROTOCOL_IBUS`: 遥控器 IBUS 协议（0x20 0x40 帧头，16位校验）。

---

## 重要宏定义

```c
#define UART_TX_BUFFER_SIZE 64          // 发送环形缓冲区大小
#define UART_RX_BUFFER_SIZE 64          // 接收环形缓冲区大小
#define IBUS_FRAME_LEN 32               // IBUS固定帧长度
```

---

## 数据结构

### BSP_UART_NUM_e 串口编号枚举
```c
typedef enum {
    BSP_UART3 = 0,  // 对应 UART3 (通常用于舵机)
    BSP_UART6,      // 对应 UART6 (通常用于上位机)
    BSP_UART7,      // 对应 UART7
    BSP_UART8,      // 对应 UART8
    BSP_UART_MAX
} BSP_UART_NUM_e;
```

### 数据包结构体
- `ServoPacket_t`: 包含 ID、指令、参数数组（最大8字节）及有效性标志。
- `IbusPacket_t`: 原始32字节IBUS帧与有效性标志。

---

## 用户层API (UartModule.h) 【推荐使用】

### 1. 数据接收
- `UartModule_HasServoPacket(uart_num)`: 检查是否有完整舵机包。
- `UartModule_GetServoPacket(uart_num, packet)`: 获取并解析舵机包。
- `UartModule_ClearPacket(uart_num)`: 手动清除舵机数据包标志。
- `UartModule_HasIbusPacket(uart_num)`: 检查是否有完整IBUS包。
- `UartModule_GetIbusPacket(uart_num, packet)`: 获取IBUS包（原始32字节）。
- `UartModule_ClearIbusPacket(uart_num)`: 手动清除IBUS数据包标志。

### 2. 数据发送
- `UartModule_SendServoCmd(uart_num, id, cmd, params, len)`: 构建并发送舵机命令。
- `UartModule_SendRaw(uart_num, data, len)`: 发送不带协议封装的原始字节流。

### 3. 配置与状态
- `UartModule_SetProtocol(uart_num, type)`: 运行时切换串口协议。
- `UartModule_GetFrameCount(uart_num)`: 获取缓冲区中当前有效的完整帧数量。

---

## 典型使用示例

### 舵机双向通信
```c
// 发送控制命令
uint8_t move_params[] = {0xE8, 0x03}; // 目标位置1000
UartModule_SendServoCmd(BSP_UART3, 1, 0x03, move_params, 2);

// 处理反馈
ServoPacket_t rx_pkt;
if (UartModule_HasServoPacket(BSP_UART3)) {
    if (UartModule_GetServoPacket(BSP_UART3, &rx_pkt)) {
        // 处理 rx_pkt.params...
    }
}
```

### IBUS协议接收
```c
IbusPacket_t pkt;
if (UartModule_HasIbusPacket(BSP_UART6)) {
    if (UartModule_GetIbusPacket(BSP_UART6, &pkt)) {
        // 处理 pkt.data
    }
}
```

---

## 注意事项

1. **初始化**: 必须调用 `BSP_UART_Init()` 来初始化缓冲区和硬件中断。
2. **CRC校验**: 
   - `PROTOCOL_SERVO_NO_MCU` 使用 8位 CRC（`CRC = ~(Sum(data)) & 0xFF`）。
   - `PROTOCOL_IBUS` 使用 16位校验（`Checksum = 0xFFFF - Sum(frame[0..29])`）。
3. **并发安全**: 发送操作是线程安全的（通过 `isSending` 标志协调环形缓冲区读取）。
4. **中断恢复**: 若因过载导致串口停机，系统会自动通过 `UART_RestartRx` 尝试恢复。

---

## 更新日志

- **2026-01-03**:
  - 扩展串口支持至 UART8。
  - 优化协议解析结构，IBUS 与舵机协议分离。
  - UART6 使用 DMA 接收固定32字节 IBUS 帧。

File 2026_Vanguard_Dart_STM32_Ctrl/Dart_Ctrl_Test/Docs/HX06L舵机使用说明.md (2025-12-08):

# HX06L 总线舵机使用说明文档

## 文件信息

- **头文件**: `User/inc/HX06L.h`
- **源文件**: `User/src/HX06L.c`
- **作用**: 换弹结构总线舵机控制，支持双协议切换

---

## 功能概述

本模块封装了 HX06L 总线舵机的控制功能，支持两种通信协议，通过宏定义切换。

### 核心功能

1. **双协议支持** - 支持无 MCU 驱动板协议和有 MCU 控制板协议
2. **单舵机控制** - 控制单个舵机转动到指定角度
3. **多舵机控制** - 同时控制多个舵机（控制板协议）
4. **动作组控制** - 运行/停止预设动作组（控制板协议）
5. **舵机卸力** - 控制舵机马达掉电卸力

---

## 协议选择

通过 `HX06L.h` 中的宏定义选择协议：

```c
// 协议选择宏
#define other_mcu_forcing  1  // 0=无MCU驱动板协议, 1=有MCU控制板协议
```

### 协议对比

| 特性 | 无 MCU 驱动板协议 (0) | 有 MCU 控制板协议 (1) |
| --- | --- | --- | --- | --- | ----- | ---- | --- | --- | --- | --- |
| 波特率 | 115200 | 9600 |
| 帧格式 | `0x55 0x55 | ID | Length | Cmd | Param | CRC` | `0x55 0x55 | Length | Cmd | Param` |
| CRC 校验 | 有 | 无 |
| 舵机 ID 位置 | 在帧头后 | 在参数中 |
| 多舵机控制 | 需逐个发送 | 单帧控制多个 |
| 动作组功能 | 不支持 | 支持 |

---

## 数据结构（有 MCU 控制板协议）

### ControlBoardCmd 控制板指令枚举

```c
typedef enum {
    CMD_SERVO_MOVE = 0x03,           // 控制任意个舵机的转动
    CMD_ACTION_GROUP_RUN = 0x06,     // 控制动作组运行
    CMD_ACTION_GROUP_STOP = 0x07,    // 停止正在运行的动作组
    CMD_ACTION_GROUP_COMPLETE = 0x08,// 动作组自然运行结束返回
    CMD_ACTION_GROUP_SPEED = 0x0B,   // 控制动作组的速度
    CMD_GET_BATTERY_VOLTAGE = 0x0F,  // 获取控制板电池电压
    CMD_MULT_SERVO_UNLOAD = 0x14,    // 控制多个舵机马达掉电卸力
    CMD_MULT_SERVO_POS_READ = 0x15   // 读取多个舵机的角度位置值
} ControlBoardCmd;
```

---

## 通用 API 函数

以下函数在两种协议下均可使用：

### 1. ServoInit()

**功能**: 舵机初始化

```c
void ServoInit(void);
```

**使用示例**:

```c
ServoInit();  // 初始化舵机
```

**注意事项**:

- 无 MCU 协议：初始化 3 个舵机(ID: 1, 2, 3)并上电
- 有 MCU 协议：发送读取电压命令测试通信

---

### 2. ServoControlPos()

**功能**: 控制单个舵机转动到指定角度

```c
void ServoControlPos(uint8_t ID, uint16_t Angle, uint16_t Time);
```

**参数说明**:

- `ID`: 舵机 ID 号 (0-253)
- `Angle`: 目标角度 (0-1000，对应 0°-240°)
- `Time`: 转动时间 (0-30000ms)

**使用示例**:

```c
// 控制1号舵机在1000ms内转到中间位置(500)
ServoControlPos(1, 500, 1000);

// 控制2号舵机在500ms内转到最大角度(1000)
ServoControlPos(2, 1000, 500);
```

**角度换算**:

```
角度值 = 实际角度(°) × 1000 / 240
实际角度(°) = 角度值 × 240 / 1000
```

| 角度值 | 实际角度 |
| --- | --- |
| 0 | 0° |
| 500 | 120° |
| 1000 | 240° |

---

## 有 MCU 控制板协议专用函数

以下函数仅在 `other_mcu_forcing = 1` 时可用：

### 3. ServoControlMulti()

**功能**: 同时控制多个舵机转动

```c
void ServoControlMulti(uint8_t servo_num, uint8_t *servo_ids, uint16_t *angles, uint16_t time);
```

**参数说明**:

- `servo_num`: 舵机个数
- `servo_ids`: 舵机 ID 数组指针
- `angles`: 角度数组指针 (0-1000)
- `time`: 转动时间 (ms)

**使用示例**:

```c
uint8_t ids[] = {1, 2, 3};
uint16_t angles[] = {500, 800, 300};

// 控制3个舵机在1000ms内同时转到指定位置
ServoControlMulti(3, ids, angles, 1000);
```

---

### 4. ServoRunActionGroup()

**功能**: 运行预设的动作组

```c
void ServoRunActionGroup(uint8_t group_num, uint16_t run_times);
```

**参数说明**:

- `group_num`: 动作组编号
- `run_times`: 运行次数 (0 表示无限次循环)

**使用示例**:

```c
// 运行8号动作组1次
ServoRunActionGroup(8, 1);

// 运行2号动作组无限次
ServoRunActionGroup(2, 0);
```

---

### 5. ServoStopActionGroup()

**功能**: 停止当前正在运行的动作组

```c
void ServoStopActionGroup(void);
```

**使用示例**:

```c
ServoStopActionGroup();  // 停止动作组
```

---

### 6. ServoSetActionGroupSpeed()

**功能**: 设置动作组运行速度

```c
void ServoSetActionGroupSpeed(uint8_t group_num, uint16_t speed_percent);
```

**参数说明**:

- `group_num`: 动作组编号 (0xFF 表示所有动作组)
- `speed_percent`: 速度百分比 (100=原速，200=2 倍速，50=0.5 倍速)

**使用示例**:

```c
// 设置8号动作组以50%速度运行
ServoSetActionGroupSpeed(8, 50);

// 设置所有动作组以3倍速运行
ServoSetActionGroupSpeed(0xFF, 300);
```

**注意事项**:

- 速度设置关机不保存，每次开机需重新设置
- 超过舵机极限速度的设置无效

---

### 7. ServoUnloadMulti()

**功能**: 控制多个舵机卸力（马达掉电）

```c
void ServoUnloadMulti(uint8_t servo_num, uint8_t *servo_ids);
```

**参数说明**:

- `servo_num`: 舵机个数
- `servo_ids`: 舵机 ID 数组指针

**使用示例**:

```c
uint8_t ids[] = {1, 2, 3};

// 控制1,2,3号舵机卸力
ServoUnloadMulti(3, ids);
```

**注意事项**:

- 卸力后舵机可以用手自由转动
- 重新发送位置指令后舵机会重新上电

---

### 8. ServoGetBatteryVoltage()

**功能**: 获取控制板电池电压

```c
void ServoGetBatteryVoltage(void);
```

**使用示例**:

```c
ServoGetBatteryVoltage();
// 电压值通过接收回调获取，单位为毫伏(mV)
```

---

## 通信协议详解

### 有 MCU 控制板协议帧格式

```
帧头   | 数据长度 | 指令 | 参数1 | ... | 参数N
0x55 0x55  Length   Cmd   Prm1  ...   PrmN
```

**数据长度计算**: `Length = 参数个数N + 2`

#### 控制舵机转动 (CMD_SERVO_MOVE = 0x03)

```
0x55 0x55 | Length | 0x03 | 舵机个数 | 时间L | 时间H | [ID | 角度L | 角度H] × N
```

**示例** - 控制 1 号舵机在 1000ms 内转到 800 位置：

```
0x55 0x55 0x08 0x03 0x01 0xE8 0x03 0x01 0x20 0x03
```

**示例** - 控制 2 号和 9 号舵机在 800ms 内都转到 800 位置：

```
0x55 0x55 0x0B 0x03 0x02 0x20 0x03 0x02 0x20 0x03 0x09 0x20 0x03
```

---

### 无 MCU 驱动板协议帧格式

```
帧头   | ID | 数据长度 | 指令 | 参数 | 校验和
0x55 0x55  ID  Length   Cmd   Param  CRC
```

**数据长度计算**: `Length = 参数长度 + 3`

**CRC 校验算法**: `CRC = ~(SUM(ID到Param)) & 0xFF`

---

## 典型应用场景

### 场景 1: 换弹结构控制（有 MCU 控制板）

```c
// 初始化（BSP_UART_Init已在main中调用，UART6默认SERVO协议）
ServoInit();

// 换弹动作序列
void ReloadAction(void) {
    // 1. 打开弹仓
    ServoControlPos(1, 800, 500);
    vTaskDelay(600);

    // 2. 推弹
    ServoControlPos(2, 500, 300);
    vTaskDelay(400);

    // 3. 关闭弹仓
    ServoControlPos(1, 200, 500);
    vTaskDelay(600);
}

// 或使用预设动作组
void ReloadActionGroup(void) {
    ServoRunActionGroup(1, 1);  // 运行1号动作组1次
}
```

### 场景 2: 同步控制多舵机

```c
uint8_t servo_ids[] = {1, 2, 3};
uint16_t angles[] = {500, 500, 500};

// 所有舵机同步移动到中间位置
ServoControlMulti(3, servo_ids, angles, 1000);
```

### 场景 3: 舵机调试

```c
// 卸力后手动调整位置
uint8_t ids[] = {1, 2, 3};
ServoUnloadMulti(3, ids);

// 调整完成后恢复控制
ServoControlPos(1, 500, 1000);
```

---

## 使用注意事项

1. **初始化顺序**

   - 先调用 `BSP_UART_Init()` 初始化串口（自动启动接收）
   - UART6 默认配置为 SERVO 协议，无需额外设置
   - 再调用 `ServoInit()` 初始化舵机

2. **协议选择**

   - 修改宏 `other_mcu_forcing` 后需重新编译
   - 确保硬件波特率与协议匹配

3. **UART 配置**

   - 无 MCU 协议: 115200 波特率
   - 有 MCU 协议: 9600 波特率
   - 使用 BSP_UART6 进行通信（默认 SERVO 协议）

4. **角度范围**

   - 有效范围: 0-1000 (对应 0°-240°)
   - 超出范围可能导致舵机异常

4. **时间参数**

   - 有效范围: 0-30000ms
   - 时间为 0 时舵机以最快速度转动

5. **延时处理**

   - 发送命令后建议等待 1-2ms
   - 使用 `vTaskDelay()` 而非 `HAL_Delay()`

6. **动作组（仅控制板协议）**
   - 动作组需预先通过上位机下载到控制板
   - 速度设置关机不保存

---

## 硬件连接

| 信号 | MCU 引脚 | 说明 |
| ---- | --- | --- |
| TX | UART6_TX | 发送到舵机/控制板 |
| RX | UART6_RX | 接收舵机/控制板反馈 |
| GND  | GND | 共地 |

---

## 常见问题

**Q: 舵机没有反应？**
A:

1. 检查波特率是否正确配置
2. 检查 TX/RX 连接是否正确
3. 确认舵机 ID 是否正确
4. 无 MCU 协议需先调用 `ServoInit()` 上电

**Q: 多个舵机如何同时运动？**
A:

- 控制板协议: 使用 `ServoControlMulti()` 函数
- 驱动板协议: 需要快速连续发送多个命令

**Q: 如何切换协议？**
A: 修改 `HX06L.h` 中的 `other_mcu_forcing` 宏并重新编译

**Q: 动作组如何创建？**
A: 使用控制板配套的上位机软件创建并下载到控制板

---

## 相关模块

- **BSP_UART**: 串口通信底层支持
- **FreeRTOS**: 任务延时功能

---

## 更新日志

| 日期 | 更新内容 |
| --- | --- |
| 2025/11/24 | 创建基础版本 |
| 2025/12/05 | 添加有 MCU 控制板协议支持 |
| 2025/12/05 | 添加双协议切换宏 |
| 2025/12/06 | 移除发送函数中不必要的协议设置 |
| 2025/12/08 | 更新初始化说明（BSP_UART_Init 自动启动接收和设置协议） |

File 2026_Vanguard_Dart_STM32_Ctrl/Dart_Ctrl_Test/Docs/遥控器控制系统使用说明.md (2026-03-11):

# 遥控器控制系统使用说明

## 概述

本文档描述飞镖系统的遥控器（FS-I6 + IA6B接收机）控制模块的设计与使用方法。

**核心文件**：

- `User/inc/ControlState.h` - 控制状态结构体与API声明
- `User/src/ControlState.c` - IbusTask、ControlTask实现
- `User/src/IA6B.c` - IBUS协议解析

---

## 一、模式状态机

```
┌─────────────────────────────────────────────────────────────────┐
│                        上电初始化                                │
│                            │                                    │
│                            ▼                                    │
│              ┌─────────────────────────────┐                    │
│              │   CTRL_MODE_NORMAL_SINGLE   │◄────────────────┐  │
│              │      （正常单发模式）         │                 │  │
│              └──────────────┬──────────────┘                 │  │
│                             │                                 │  │
│                   单发流程完成后                               │  │
│              ShootTask调用StartDebugWindow()                  │  │
│                             │                                 │  │
│                             ▼                                 │  │
│              ┌─────────────────────────────┐      20s超时     │  │
│              │   CTRL_MODE_DEBUG_TIMER     │─────────────────►│  │
│              │     （调试窗口模式）          │                 │  │
│              └──────────────┬──────────────┘                 │  │
│                             │                                 │  │
│                    SWB=0 拨下                                  │  │
│                             │                                 │  │
│                             ▼                                 │  │
│              ┌─────────────────────────────┐                 │  │
│              │      手动控制生效            │      SWB=1      │  │
│              │   ControlTask下发电机命令    │─────────────────┘  │
│              └─────────────────────────────┘                    │
└─────────────────────────────────────────────────────────────────┘
```

### 模式说明

| 模式 | 枚举值 | 触发条件 | 行为 |
| --- | --- | --- | --- |
| 正常单发 | `CTRL_MODE_NORMAL_SINGLE` | 默认状态 | 任务流程接管电机，忽略摇杆 |
| 调试窗口 | `CTRL_MODE_DEBUG_TIMER` | 单发完成后20s内 | 允许SWB=0进入手动控制 |

**重要**：调试窗口外，SWB=0 无效，不会进入手动模式。

---

## 二、通道映射

### 2.1 摇杆与开关分配

| RawChannel | 遥控器位置 | 类型 | 控制目标 | 电机 |
| --- | --- | --- | --- | --- |
| `[0]` | 右摇杆左右 | 回中 | YAW角度  | DM4310 |
| `[1]` | 右摇杆上下 | 不回中 | 储能位置 | DM3519 L/R |
| `[2]` | 左摇杆上下 | 不回中 | 扳机位置 | RM2006 |
| `[3]` | 左摇杆左右 | 回中 | 3508位置 | RM3508 |
| `[4]` | SWB | 两段开关 | 模式切换 | - |
| `[5]` | SWC | 三段开关 | 扳机覆盖 | RM2006 |

### 2.2 控制逻辑

#### 回中摇杆（增量式）

```c
// 归一化：norm = (raw - 1500) / 500，死区 ±5%
// 目标更新：target += norm * weight * dt
```

#### 不回中摇杆（三段式）

```c
// 方向判定：raw > 1700 -> +1, raw < 1300 -> -1, 否则 0
// 目标更新：target += dir * weight * dt
```

#### 开关状态

- **SWB**：`1000 -> 1`（正常），`2000 -> 0`（手动）
- **SWC**：`1000 -> 1`，`1500 -> 0`（扳机上），`2000 -> -1`（扳机下）

---

## 三、任务架构

### 3.1 任务列表

| 任务名 | 优先级  | 周期 | 栈大小 | 职责 |
| --- | --- | --- | --- | --- |
| IbusTask | High | 5ms | 512B | 解析IBUS，更新`g_ControlInput` |
| ControlTask | Normal  | 10ms | 1KB | 计算目标增量，下发电机命令 |
| StoreEnergyTask | Normal1 | 事件驱动 | 512B | 储能电机状态机 |
| ShootTask | Normal  | 事件驱动 | 512B | 舵机发射控制 |
| StateSetTask | Normal  | 一次性 | 2KB | 初始化YAW和扳机位置 |

### 3.2 数据流

```
┌──────────┐    g_ControlInput    ┌─────────────┐    电机命令    ┌──────────┐
│ IbusTask │ ──────────────────► │ ControlTask │ ────────────► │  电机    │
└──────────┘                      └─────────────┘               └──────────┘
     │                                   │
     │ IA6B_ProcessIbusPacket()          │ DmMotorSendCfg()
     │ 解析RawChannel[]                   │ RmMotorPID_Calc()
     ▼                                   ▼
┌──────────┐                      ┌─────────────┐
│ UART DMA │                      │g_ControlState│
└──────────┘                      └─────────────┘
```

---

## 四、参数配置

所有可调参数定义在 `User/inc/ControlState.h`：

### 4.1 任务周期

```c
#define IBUS_TASK_PERIOD_MS     5     // IbusTask周期
#define CTRL_TASK_PERIOD_MS     10    // ControlTask周期
#define DEBUG_WINDOW_MS         20000 // 调试窗口时间（20秒）
```

### 4.2 摇杆参数

```c
#define STICK_CENTER            1500  // 摇杆中心值
#define STICK_RANGE             500   // 摇杆范围
#define STICK_DEADZONE          0.05f // 死区（±5%）
#define NON_CENTER_HIGH         1700  // 非回中高位阈值
#define NON_CENTER_LOW          1300  // 非回中低位阈值
```

### 4.3 电机权重（目标增量/秒）

```c
#define WEIGHT_YAW              30.0f   // YAW旋转速度（rad）
#define WEIGHT_TRIGGER          500.0f  // 扳机移动速度（rad）
#define WEIGHT_ENERGY           100.0f  // 储能电机速度（rad）
#define WEIGHT_LOAD3508         200.0f  // 3508位置速度（rad）
```

### 4.4 电机限幅

```c
#define YAW_MIN                 -160.0f
#define YAW_MAX                 160.0f
#define TRIGGER_MIN             -10000.0f
#define TRIGGER_MAX             0.0f
#define ENERGY_LEFT_MIN         -900.0f
#define ENERGY_LEFT_MAX         50.0f
#define ENERGY_RIGHT_MIN        -50.0f
#define ENERGY_RIGHT_MAX        900.0f
#define LOAD3508_MIN            -20000.0f
#define LOAD3508_MAX            0.0f
```

---

## 五、典型调试场景

### 5.1 完整流程

```
1. 上电
   └─► StateSetTask 设置初始 YAW 和扳机位置
           │
2. 事件组就绪
   └─► StoreEnergyTask 开始储能状态机
           │
3. 储能完成（到达扳机位置）
   └─► ShootTask 释放舵机，发射飞镖
           │
4. 发射完成
   └─► 调用 ControlState_StartDebugWindow()
       ├─► 同步目标值与电机当前反馈（避免突跳）
       └─► 开启 20s 调试窗口
           │
5. 调试窗口内
   └─► 拨下 SWB → 遥控器接管电机控制
       ├─► 右摇杆左右 → 调节 YAW
       ├─► 右摇杆上下 → 调节储能电机
       ├─► 左摇杆上下 → 调节扳机（或用SWC覆盖）
       └─► 左摇杆左右 → 调节 3508
           │
6. 调试结束
   └─► 20s 超时或拨回 SWB → 恢复正常模式
```

### 5.2 手动调试操作

1. **等待调试窗口**：单发完成后自动开启
2. **拨下SWB**：进入手动控制模式
3. **使用摇杆**：
   - 右摇杆左右：调节云台YAW角度
   - 右摇杆上下：调节储能电机位置
   - 左摇杆上下：调节扳机位置
   - 左摇杆左右：调节3508换弹位置
4. **使用SWC**：
   - SWC中位(0)：强制扳机上移
   - SWC下位(-1)：强制扳机下移
5. **拨回SWB**：退出手动模式

---

## 六、保护机制

### 6.1 模式互斥

- 调试窗口外，SWB=0 无效
- 只有在 `debug_window_active` 为 true 时才允许手动控制

### 6.2 内层循环检测

```c
// StoreEnergyTask 内部等待循环可被手动模式打断
while (temp)
{
    if (ControlState_IsManualOverride()) break;
    // ...
}
```

### 6.3 目标同步

```c
// 进入手动模式瞬间，目标值对齐电机当前反馈
if (manual_override && !prev_manual_override)
{
    SyncTargetsWithMotorFeedback();
}
```

---

## 七、API 参考

### 7.1 初始化

```c
void ControlState_Init(void);           // 初始化控制状态
void ControlState_CreateTasks(void);    // 创建 IbusTask 和 ControlTask
```

### 7.2 状态查询

```c
CtrlMode_e ControlState_GetMode(void);        // 获取当前模式
bool ControlState_IsManualOverride(void);     // 是否处于手动覆盖
```

### 7.3 目标设置（供其他任务使用）

```c
void ControlState_SetYawTarget(float target);
void ControlState_SetTriggerTarget(float target);
void ControlState_SetEnergyTarget(float left, float right);
void ControlState_SetLoad3508Target(float target);
```

### 7.4 调试窗口

```c
void ControlState_StartDebugWindow(uint32_t duration_ms);  // 开启调试窗口
void ControlState_MarkSingleShotDone(void);                // 标记单发完成
```

---

## 八、故障排查

| 现象 | 可能原因 | 解决方法 |
| --- | --- | --- |
| SWB拨下无反应 | 不在调试窗口内 | 等待单发完成后再操作 |
| 电机突跳 | 目标值未同步 | 检查 `SyncTargetsWithMotorFeedback()` |
| 摇杆无响应 | IBUS数据无效 | 检查 `g_ControlInput.data_valid` |
| 调节速度太快/慢 | 权重参数不合适 | 修改 `WEIGHT_*` 宏定义 |
| 电机到达极限 | 限幅参数错误 | 修改 `*_MIN/*_MAX` 宏定义 |

---

## 九、修改历史

| 日期 | 版本 | 修改内容 |
| --- | ---- | --- |
| 2026-01-23 | v1.0 | 初始版本，实现基本控制框架 |

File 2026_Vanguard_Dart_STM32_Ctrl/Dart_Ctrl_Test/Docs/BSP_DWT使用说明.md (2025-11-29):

# BSP_DWT 使用说明文档

## 文件信息
- **头文件**: `Bsp/inc/bsp_dwt.h`
- **源文件**: `Bsp/src/bsp_dwt.c`
- **作者**: Wang Hongxi
- **版本**: V1.1.0
- **作用**: DWT(数据观察点与跟踪)高精度计时模块

---

## 功能概述

DWT(Data Watchpoint and Trace)是ARM Cortex-M内核的调试组件，本模块利用其CYCCNT寄存器实现高精度的时间测量和延时功能。

### 核心功能
1. **高精度延时** - 微秒(μs)、毫秒(ms)、秒(s)级延时
2. **时间测量** - 计算代码执行时间
3. **系统时间** - 获取系统运行总时长
4. **时间差计算** - 计算两次调用之间的时间间隔

---

## 数据结构

### DWT_clock_t 系统时间结构体
```c
typedef struct {
    uint32_t s;   // 秒
    uint16_t ms;  // 毫秒
    uint16_t us;  // 微秒
} DWT_clock_t;

extern DWT_clock_t system_time;  // 全局系统时间变量
```

---

## 核心API函数

### 1. DWT_Init()
**功能**: 初始化DWT计时器
```c
void DWT_Init(uint32_t CPU_Freq_mHz);
```

**参数说明**:
- `CPU_Freq_mHz`: CPU频率(单位: MHz)，例如168表示168MHz

**使用示例**:
```c
DWT_Init(168);  // 初始化DWT，CPU频率为168MHz
```

**注意事项**:
- 必须在使用其他DWT功能前调用
- 通常在系统初始化时调用一次即可

---

### 2. 延时函数

#### DWT_Delay()
**功能**: 秒级精确延时
```c
void DWT_Delay(float Delay);
```

**参数说明**:
- `Delay`: 延时时间(单位: 秒)，支持小数

**使用示例**:
```c
DWT_Delay(0.5);   // 延时0.5秒
DWT_Delay(1.0);   // 延时1秒
```

---

#### DWT_Delay_us()
**功能**: 微秒级精确延时
```c
void DWT_Delay_us(uint32_t us);
```

**参数说明**:
- `us`: 延时时间(单位: 微秒)
- 范围: 0-16777215 μs (约16.7秒 @ 100MHz)

**使用示例**:
```c
DWT_Delay_us(100);   // 延时100微秒
DWT_Delay_us(1000);  // 延时1毫秒
```

**注意事项**:
- 最大延时时间受CPU频率限制
- 100MHz: 最长约16.7秒
- 200MHz: 最长约8.3秒

---

#### DWT_Delay_ms()
**功能**: 毫秒级精确延时
```c
void DWT_Delay_ms(uint32_t ms);
```

**参数说明**:
- `ms`: 延时时间(单位: 毫秒)
- 范围: 0-4294967 ms (约4294秒)

**使用示例**:
```c
DWT_Delay_ms(10);    // 延时10毫秒
DWT_Delay_ms(1000);  // 延时1秒
```

---

### 3. 时间测量函数

#### DWT_GetDeltaT()
**功能**: 获取两次调用之间的时间差(float精度)
```c
float DWT_GetDeltaT(uint32_t *cnt_last);
```

**参数说明**:
- `cnt_last`: 上次计数值指针(函数会自动更新)

**返回值**: 时间差(单位: 秒)

**使用示例**:
```c
uint32_t cnt = 0;
float dt;

// 第一次调用
dt = DWT_GetDeltaT(&cnt);  // dt为0或很小

// 执行某些操作...

// 第二次调用
dt = DWT_GetDeltaT(&cnt);  // dt为两次调用之间的时间差(秒)
```

---

#### DWT_GetDeltaT64()
**功能**: 获取两次调用之间的时间差(double精度)
```c
double DWT_GetDeltaT64(uint32_t *cnt_last);
```

**参数说明**:
- `cnt_last`: 上次计数值指针

**返回值**: 时间差(单位: 秒)，double精度

**使用场景**: 需要更高精度的时间测量

---

### 4. 系统运行时间函数

#### DWT_GetTimeline_s()
**功能**: 获取系统运行总时长(秒)
```c
float DWT_GetTimeline_s(void);
```

**返回值**: 系统运行时间(单位: 秒)

**使用示例**:
```c
float runtime = DWT_GetTimeline_s();
printf("系统已运行: %.2f 秒\n", runtime);
```

---

#### DWT_GetTimeline_ms()
**功能**: 获取系统运行总时长(毫秒)
```c
float DWT_GetTimeline_ms(void);
```

**返回值**: 系统运行时间(单位: 毫秒)

**使用示例**:
```c
float runtime = DWT_GetTimeline_ms();
printf("系统已运行: %.2f 毫秒\n", runtime);
```

---

#### DWT_GetTimeline_us()
**功能**: 获取系统运行总时长(微秒)
```c
uint64_t DWT_GetTimeline_us(void);
```

**返回值**: 系统运行时间(单位: 微秒)

**使用示例**:
```c
uint64_t runtime = DWT_GetTimeline_us();
printf("系统已运行: %llu 微秒\n", runtime);
```

---

## 实用宏定义

### TIME_ELAPSE 宏
**功能**: 自动测量代码块执行时间
```c
#define TIME_ELAPSE(dt, code)
```

**使用示例**:
```c
float execution_time;

TIME_ELAPSE(execution_time, {
    // 要测量的代码
    for(int i = 0; i < 1000; i++) {
        // 某些操作
    }
});

printf("代码执行时间: %.6f 秒\n", execution_time);
```

---

## 典型应用场景

### 场景1: 精确控制延时
```c
// 初始化
DWT_Init(168);

// 精确延时
DWT_Delay_us(100);   // 延时100μs
DWT_Delay_ms(10);    // 延时10ms
```

### 场景2: 测量函数执行时间
```c
uint32_t cnt = 0;
float exec_time;

DWT_GetDeltaT(&cnt);  // 开始计时

// 执行要测量的函数
my_function();

exec_time = DWT_GetDeltaT(&cnt);  // 获取执行时间
printf("函数执行时间: %.6f 秒\n", exec_time);
```

### 场景3: 周期性任务时间控制
```c
uint32_t last_time = 0;
float dt;

while(1) {
    dt = DWT_GetDeltaT(&last_time);
    
    if(dt >= 0.01) {  // 每10ms执行一次
        // 执行周期任务
        periodic_task();
    }
}
```

### 场景4: 获取系统运行时间
```c
float uptime_s = DWT_GetTimeline_s();
printf("系统运行时间: %.2f 秒\n", uptime_s);
```

---

## 实现原理

### DWT CYCCNT寄存器
- **CYCCNT**: 32位递增计数器，每个CPU周期加1
- **优势**: 硬件实现，高精度，不占用定时器资源
- **溢出处理**: 模块自动处理32位溢出，支持长时间运行

### 时间计算公式
```
时间(秒) = CYCCNT计数值 / CPU频率(Hz)
```

例如: CPU频率168MHz，计数1680000次 = 0.01秒(10ms)

---

## 使用注意事项

1. **必须先初始化**
   - 在使用任何DWT功能前必须调用`DWT_Init()`
   - 传入正确的CPU频率值

2. **延时精度**
   - DWT延时是CPU周期级精度
   - 比HAL_Delay()更精确
   - 不受中断影响(除非中断时间过长)

3. **计数器溢出**
   - 模块已处理32位计数器溢出问题
   - 支持长时间连续运行

4. **中断影响**
   - 如果中断处理时间过长，可能影响延时精度
   - 建议在关键延时期间关闭非必要中断

5. **资源占用**
   - 不占用硬件定时器
   - 仅使用DWT调试组件

---

## 性能对比

| 延时方式 | 精度 | 最小延时 | 资源占用 | 备注 |
|---|---|---|---|---|
| HAL_Delay() | 毫秒级 | 1ms | SysTick定时器 | 系统延时 |
| DWT_Delay_us() | 微秒级 | 1μs | DWT组件 | 高精度延时 |
| DWT_Delay_ms() | 微秒级 | 1ms | DWT组件 | 高精度延时 |

---

## 相关模块

- **CanMotor**: 电机控制中可能需要精确的时间测量
- **DM_Motor**: 达妙电机发送间隔使用DWT延时
- **所有需要精确计时的模块**

---

## 更新日志

- V1.1.0: 完善了延时函数，增加了微秒和毫秒延时
- 支持float和double精度的时间差计算
- 自动处理计数器溢出

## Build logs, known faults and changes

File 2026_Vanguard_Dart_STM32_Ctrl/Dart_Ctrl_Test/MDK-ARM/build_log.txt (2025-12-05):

*** Using Compiler 'V5.06 update 7 (build 960)', folder: 'D:\KEIL\Core\ARM\ARMCC\Bin'
Build target 'Dart_Ctrl'
"Dart_Ctrl\Dart_Ctrl.axf" - 0 Error(s), 0 Warning(s).
Build Time Elapsed:  00:00:00

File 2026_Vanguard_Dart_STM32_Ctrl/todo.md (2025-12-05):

# 飞镖任务计划表

> **当前日期：2025年12月5日（星期五）**

| 序号 | 任务名称 | 时间范围 | 任务内容 |
|---|---|---|---|
| 1 | 机械任务1：镖架基础部分全部装完 | 11.24 ~ 11.30  | 镖架基础部分全部装完：更换同步带（需确认到货及安装时间）<已完成> |
| 2 | 机械任务2：换弹结构完善 | 11.27 ~ 12.15  | - 重打打印件，确定新换弹结构是否可用<br>- 11.27：电控任务1成功驱动M3508后，总线舵机开始协同测试<br>- 12.8前：完成换弹结构的全部设计 + 装配<装配完成，等待测试夹爪安装><br>- 12.15前：完成换弹结构的全部测试 | |
| 3 | 电控任务1：单独模块驱动 | 11.24 ~ 12.8 | **要求**：让电机按“预设速度”转动“预设距离”<br>- 11.24 ~ 11.27：总线舵机（需搭配硬件任务：设计降压电路），M2006（与机械协同测试换弹结构）<br>- 11.28 ~ 12.8：M3508，扳机舵机（PWM），DM3510/4310 |
| 4 | 电控任务2：和机械协同测试，初步确定“当前”换弹结构是否可用 | 11.27 ~ 11.30  | 与机械协同测试，初步验证当前换弹结构的可行性 |
| 5 | 电控任务3：无控飞镖系统完全体 | 11.30 ~ 12.20  | - 11.30 ~ 12.12：测试基础功能（储能 + 发射）<br>- 12.20前：完成连续发射4发飞镖的完全体功能 |

---

📌 **备注**：
- 所有任务均需按时间节点推进，建议每日同步进度。
- 机械与电控任务存在强依赖关系，请加强跨组协作沟通。

---
12.07进度：

__•1 总线舵机__

💬驱动存在多个，需要重写驱动

__•2 3508换弹驱动舵机__

💬等待串级PID位置环闭环，内环速度环已闭

💬等待测量回程误差

💬等待测量换弹舵机闭环积分角度

__•3 总线舵机驱动板设计(额外任务 紧急程度为中等)__

💬基本完成PCB设计，等待打板验证

__•4 飞镖新供电板(额外任务 紧急程度为中等)__

💬第一次验证失败，被客服扯皮，准备紧急寻求火锅大佬帮助

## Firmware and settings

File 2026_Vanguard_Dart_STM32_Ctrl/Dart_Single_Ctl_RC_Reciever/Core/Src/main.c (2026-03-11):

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
/* Includes ------------------------------------------------------------------*/
#include "main.h"
#include "can.h"
#include "dma.h"
#include "tim.h"
#include "usart.h"
#include "gpio.h"

/* USER CODE BEGIN Includes */
#include "IA6B.h"
/* USER CODE END Includes */


/* USER CODE BEGIN PV */
uint8_t gRcData[256] = {0};
int16_t throttle;
int16_t roll;
int16_t pitch;
int16_t yaw;
/* USER CODE END PV */

void SystemClock_Config(void);
/* USER CODE BEGIN PFP */
void RC_Task(void)
{
  if (IA6B_ProcessIbusPacket(BSP_UART6))
  {
    // 成功解析，读取通道值
    throttle = IA6B_ReadChannel(1); // 油门
    roll = IA6B_ReadChannel(2);     // 横滚
    pitch = IA6B_ReadChannel(3);    // 俯仰
    yaw = IA6B_ReadChannel(4);      // 偏航
  }
}
/* USER CODE END PFP */

/**
 * @brief  The application entry point.
 * @retval int
 */
int main(void)
{

  /* MCU Configuration--------------------------------------------------------*/

  /* Reset of all peripherals, Initializes the Flash interface and the Systick. */
  HAL_Init();

  /* Configure the system clock */
  SystemClock_Config();

  /* Initialize all configured peripherals */
  MX_GPIO_Init();
  MX_DMA_Init();
  MX_CAN1_Init();
  MX_UART7_Init();
  MX_USART3_UART_Init();
  MX_USART6_UART_Init();
  MX_UART8_Init();
  MX_TIM12_Init();
  MX_USART1_UART_Init();
  MX_TIM8_Init();
  /* USER CODE BEGIN 2 */
  BSP_UART_Init();
  UART_SetProtocolType(BSP_UART6, PROTOCOL_IBUS);
  HAL_Delay(200);
  /* USER CODE END 2 */

  /* Infinite loop */
  /* USER CODE BEGIN WHILE */
  while (1)
  {
    RC_Task();
		HAL_Delay(10);
    /* USER CODE END WHILE */

    /* USER CODE BEGIN 3 */
  }
  /* USER CODE END 3 */
}

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
/**
 * @brief  Period elapsed callback in non blocking mode
 * @note   This function is called  when TIM4 interrupt took place, inside
 * HAL_TIM_IRQHandler(). It makes a direct call to HAL_IncTick() to increment
 * a global variable "uwTick" used as application time base.
 * @param  htim : TIM handle
 * @retval None
 */
void HAL_TIM_PeriodElapsedCallback(TIM_HandleTypeDef *htim)
{
  if (htim->Instance == TIM4)
  {
    HAL_IncTick();
  }
}

/**
 * @brief  This function is executed in case of error occurrence.
 * @retval None
 */
void Error_Handler(void)
{
  /* USER CODE BEGIN Error_Handler_Debug */
  /* User can add his own implementation to report the HAL error return state */
  __disable_irq();
  while (1)
  {
  }
  /* USER CODE END Error_Handler_Debug */
}
#ifdef USE_FULL_ASSERT
/**
 * @brief  Reports the name of the source file and the source line number
 *         where the assert_param error has occurred.
 * @param  file: pointer to the source file name
 * @param  line: assert_param error line source number
 * @retval None
 */
void assert_failed(uint8_t *file, uint32_t line)
{
  /* USER CODE BEGIN 6 */
  /* User can add his own implementation to report the file name and line number,
     ex: printf("Wrong parameters value: file %s on line %d\r\n", file, line) */
  /* USER CODE END 6 */
}
#endif /* USE_FULL_ASSERT */

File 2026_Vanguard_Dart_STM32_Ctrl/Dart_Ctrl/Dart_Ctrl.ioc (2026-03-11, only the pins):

Mcu.UserName=STM32F427IIHx
PA13.Signal=SYS_JTMS-SWDIO
PA14.Signal=SYS_JTCK-SWCLK
PB2/BOOT1.GPIO_Label=KEY
PB2/BOOT1.Signal=GPXTI2
PB6.Signal=USART1_TX
PB7.Signal=USART1_RX
PC14/OSC32_IN.Signal=RCC_OSC32_IN
PC15/OSC32_OUT.Signal=RCC_OSC32_OUT
PD0.Signal=CAN1_RX
PD1.Signal=CAN1_TX
PD8.Signal=USART3_TX
PD9.Signal=USART3_RX
PE0.Signal=UART8_RX
PE1.Signal=UART8_TX
PE11.GPIO_Label=Red
PE11.Signal=GPIO_Output
PE7.Signal=UART7_RX
PE8.Signal=UART7_TX
PF14.GPIO_Label=Green
PF14.Signal=GPIO_Output
PG1.GPIO_Label=LED1
PG1.Signal=GPIO_Output
PG14.Signal=USART6_TX
PG2.GPIO_Label=LED2
PG2.Signal=GPIO_Output
PG3.GPIO_Label=LED3
PG3.Signal=GPIO_Output
PG4.GPIO_Label=LED4
PG4.Signal=GPIO_Output
PG5.GPIO_Label=LED5
PG5.Signal=GPIO_Output
PG6.GPIO_Label=LED6
PG6.Signal=GPIO_Output
PG7.GPIO_Label=LED7
PG7.Signal=GPIO_Output
PG8.GPIO_Label=LED8
PG8.Signal=GPIO_Output
PG9.Signal=USART6_RX
PH0/OSC_IN.Signal=RCC_OSC_IN
PH1/OSC_OUT.Signal=RCC_OSC_OUT
PH2.GPIO_Label=PWR1
PH2.Signal=GPIO_Output
PH3.GPIO_Label=PWR2
PH3.Signal=GPIO_Output
PH4.GPIO_Label=PWR3
PH4.Signal=GPIO_Output
PH5.GPIO_Label=PWR4
PH5.Signal=GPIO_Output
PH6.Signal=S_TIM12_CH1
PI2.Signal=S_TIM8_CH4

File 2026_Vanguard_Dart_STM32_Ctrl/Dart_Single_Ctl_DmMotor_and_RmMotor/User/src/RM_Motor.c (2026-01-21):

/*****************************************************
 * RM电机（大疆电机）控制模块
 * 适配M3508、M2006、GM6020等系列电机
 *
 * note:M3508 -> 19.2减速比
 *      M2006 -> 36.0减速比
 *      GM6020 -> 1.0减速比
 * --------------------------------------------------
 * RM电机说明：
 * 大疆电机的注册同一系列电调最多是4个
 * 同一CAN总线上挂载的大疆电调（只有一个系列电调最多是8个）
 * 如果是C610和C620都有，则二者均为4个即为最大值
 * --------------------------------------------------
 * 面向对象设计说明：
 * 使用 RM_MotorClass_t 作为电机"类"，包含：
 * - 电机默认参数（减速比、最大电流、电流转换系数）
 * - 虚函数表（初始化、解算、发送控制、PID计算等）
 * 预定义 RM_M2006_Class、RM_M3508_Class、RM_GM6020_Class 三个类实例
 ****************************************************/

#include "RM_Motor.h"
#include "CanMotor.h"
#include <stdbool.h>
// #include "usart.h"
#include <stdio.h>

// 直接访问电机管理器（减少函数调用开销）
extern MotorManager_t MotorManager;

float output = 0.0f;

#define CtrlMotorLen 8     // 电机控制报文长度默认给8
#define RM_MOTOR_MAX_NUM 2 // 最大电机数量

/*============================== 预计算常量（优化除法为乘法） ==============================*/
#define ECD_TO_DEGREE (360.0f / 8192.0f)                       // 编码器转角度: 0.0439453125f
#define RM_M2006_CURRENT_INV (1.0f / RM_M2006_CURRENT_RATIO)   // M2006电流倒数
#define RM_M3508_CURRENT_INV (1.0f / RM_M3508_CURRENT_RATIO)   // M3508电流倒数
#define RM_GM6020_CURRENT_INV (1.0f / RM_GM6020_CURRENT_RATIO) // GM6020电流倒数

/*============================== 静态函数声明（私有方法） ==============================*/

// 通用解算函数（内部）- 参数为电流系数倒数（优化版本）
static void RM_Motor_CalculateCommon(MotorTypeDef *motor, float current_inv);

// M2006专用函数
static void RM_M2006_InitInternal(MotorTypeDef *motor, uint8_t id);
static void RM_M2006_CalculateInternal(MotorTypeDef *motor);

// M3508专用函数
static void RM_M3508_InitInternal(MotorTypeDef *motor, uint8_t id);
static void RM_M3508_CalculateInternal(MotorTypeDef *motor);

// GM6020专用函数
static void RM_GM6020_InitInternal(MotorTypeDef *motor, uint8_t id);
static void RM_GM6020_CalculateInternal(MotorTypeDef *motor);

// 通用发送控制和PID计算
static uint8_t RM_Motor_SendControlInternal(MotorTypeDef *motor);
static float RM_Motor_PIDCalcInternal(MotorTypeDef *motor, float target);

/*============================== 电机类静态实例定义 ==============================*/

/// @brief M2006电机类（C610电调）
const RM_MotorClass_t RM_M2006_Class = {
    .name = "M2006",
    .model = RmM2006,
    .gear_ratio = RM_M2006_GEAR_RATIO,
    .max_current = RM_M2006_MAX_CURRENT,
    .current_ratio = RM_M2006_CURRENT_RATIO,
    .tx_base_addr = g_RM_MOTOR_BIAS_ADDR_2006,
    .id_min = 1,
    .id_max = 4,
    .init = RM_M2006_InitInternal,
    .calculate = RM_M2006_CalculateInternal,
    .send_control = RM_Motor_SendControlInternal,
    .pid_calc = RM_Motor_PIDCalcInternal,
};

/// @brief M3508电机类（C620电调）
const RM_MotorClass_t RM_M3508_Class = {
    .name = "M3508",
    .model = RmM3508,
    .gear_ratio = RM_M3508_GEAR_RATIO,
    .max_current = RM_M3508_MAX_CURRENT,
    .current_ratio = RM_M3508_CURRENT_RATIO,
    .tx_base_addr = g_RM_MOTOR_BIAS_ADDR_3508,
    .id_min = 1,
    .id_max = 4,
    .init = RM_M3508_InitInternal,
    .calculate = RM_M3508_CalculateInternal,
    .send_control = RM_Motor_SendControlInternal,
    .pid_calc = RM_Motor_PIDCalcInternal,
};

/// @brief GM6020电机类
const RM_MotorClass_t RM_GM6020_Class = {
    .name = "GM6020",
    .model = RmGM6020,
    .gear_ratio = RM_GM6020_GEAR_RATIO,
    .max_current = RM_GM6020_MAX_CURRENT,
    .current_ratio = RM_GM6020_CURRENT_RATIO,
    .tx_base_addr = g_RM_MOTOR_BIAS_ADDR_6020,
    .id_min = 1,
    .id_max = 7,
    .init = RM_GM6020_InitInternal,
    .calculate = RM_GM6020_CalculateInternal,
    .send_control = RM_Motor_SendControlInternal,
    .pid_calc = RM_Motor_PIDCalcInternal,
};

/*============================== 面向对象接口实现 ==============================*/

/// @brief 使用指定的电机类创建电机实例
void RM_Motor_Create(MotorTypeDef *motor, const RM_MotorClass_t *motor_class, uint8_t id)
{
    if (motor == NULL || motor_class == NULL)
        return;

    if (id < motor_class->id_min || id > motor_class->id_max)
        return;

    // 关联电机类
    motor->motor_class.rm_motor_class = motor_class;

    // 调用类的初始化函数
    if (motor_class->init != NULL)
    {
        motor_class->init(motor, id);
    }
}

/// @brief 调用电机的解算函数
void RM_Motor_Calculate(MotorTypeDef *motor)
{
    if (motor == NULL)
        return;

    // 优先使用类的虚函数表
    if (motor->motor_class.rm_motor_class != NULL && motor->motor_class.rm_motor_class->calculate != NULL)
    {
        motor->motor_class.rm_motor_class->calculate(motor);
        return;
    }

    // if (motor->calculate != NULL)
    // {
    //     motor->calculate(motor);
    // }
}

/// @brief 调用电机的发送控制函数
uint8_t RM_Motor_SendControl(MotorTypeDef *motor)
{
    if (motor == NULL)
        return 0;

    // 优先使用类的虚函数表
    if (motor->motor_class.rm_motor_class != NULL && motor->motor_class.rm_motor_class->send_control != NULL)
    {
        return motor->motor_class.rm_motor_class->send_control(motor);
    }

    // 兼容旧接口
    if (motor->SendMotorControl != NULL)
    {
        return motor->SendMotorControl(motor);
    }

    return 0;
}

/// @brief 调用电机的PID计算函数
float RM_Motor_PIDCalc(MotorTypeDef *motor, float target)
{
    if (motor == NULL)
        return 0.0f;

    // 优先使用类的虚函数表
    if (motor->motor_class.rm_motor_class != NULL && motor->motor_class.rm_motor_class->pid_calc != NULL)
    {
        return motor->motor_class.rm_motor_class->pid_calc(motor, target);
    }

    // 默认实现
    return RM_Motor_PIDCalcInternal(motor, target);
}

/*============================== 电机初始化内部函数 ==============================*/

/// @brief 初始化RM电机基础属性（内部函数）
static void RM_Motor_InitBase(MotorTypeDef *motor, uint8_t id,
                              const RM_MotorClass_t *motor_class)
{
    memset(motor, 0, sizeof(MotorTypeDef));

    // 关联电机类（推荐通过motor_class访问虚函数）
    motor->motor_class.rm_motor_class = motor_class;

    // 基本属性
    motor->MotorID = id;
    motor->MotorInf.band = RM_MOTOR_BAND;
    motor->MotorInf.model = motor_class->model;

    // 从类中复制参数
    motor->params.gear_ratio = motor_class->gear_ratio;
    motor->params.max_current = motor_class->max_current;
    motor->params.current_ratio = motor_class->current_ratio;

    // 默认配置
    motor->config.direction_bias = 0.0f;
    motor->config.position_tolerance = 50.0f;
    motor->config.reverse = 0;

    // 绑定函数指针（已弃用，保留用于向后兼容，新代码请使用motor_class虚函数表）
    motor->SendMotorControl = RM_Motor_SendControlInternal;
    motor->calculate = motor_class->calculate;

    // CAN报文头
    motor->g_TxHeader.IDE = CAN_ID_STD;
    motor->g_TxHeader.RTR = CAN_RTR_DATA;
    motor->g_TxHeader.DLC = CtrlMotorLen;
}

static void RM_M2006_InitInternal(MotorTypeDef *motor, uint8_t id)
{
    RM_Motor_InitBase(motor, id, &RM_M2006_Class);
    motor->g_TxHeader.StdId = g_RM_MOTOR_BIAS_ADDR_2006;
}

static void RM_M3508_InitInternal(MotorTypeDef *motor, uint8_t id)
{
    RM_Motor_InitBase(motor, id, &RM_M3508_Class);
    motor->g_TxHeader.StdId = g_RM_MOTOR_BIAS_ADDR_3508;
}
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

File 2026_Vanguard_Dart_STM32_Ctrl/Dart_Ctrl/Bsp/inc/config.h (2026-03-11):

/**********************************************************
 * 文件名：config.h
 * 用途：存放一些关于整个飞镖系统工程参数的宏定义
 * 创建时间：12.15 2025
 * 创建人：邓金水
 * 数据全部经过测试得来
 * todo：等待准确的数据
 *********************************************************/
#ifndef __CONFIG_H_
#define __CONFIG_H_

#include "main.h"
#include <stdbool.h>
#include <stdint.h>
#include <arm_math.h>

/* ==================== BSP层：协议常量 ==================== */

// IBUS 协议参数
#define IA6B_CHANNEL 10                             // FS-I6通道数
#define IBUS_LENGTH 0x20                            // 协议头
#define IBUS_COMMAND 0x40                           // 协议头
#define IBUS_FRAME_LEN 32                           // IBUS固定帧长度（字节）
#define IBUS_DMA_BUFFER_LEN (IBUS_FRAME_LEN * 2)    // DMA接收缓冲区长度
#define IBUS_STREAM_BUFFER_LEN (IBUS_FRAME_LEN * 2) // IBUS流解析缓存长度

/* ==================== 控制层：通用系统参数 ==================== */

#define MOTOR_TIMEOUT_MS 5000           // 电机运动超时时间（毫秒）
#define MOTOR_DEAD_ZONE 3.0f            // 电机死区（用于位置判定）
#define MOTOR_DEADZONE_TIMEOUT_MS 1000U // 死区判定超时退出（毫秒）
#define TRIGGER_DEAD_ZONE 5.0f          // 扳机电机死区
#define SERVO_MOVE_TIME_MS 315          // 舵机转动时间（毫秒）
#define POWER_ON_DELAY_MS 100           // 上电延迟时间（毫秒）
#define RELOAD_BUFFER_MS 1000           // 换弹缓冲时间（毫秒）
#define LOAD_DEADZONE_TIMEOUT_MS 2000U  // 换弹电机缓冲时间

/* ==================== 控制层：遥控器配置 ==================== */

/*============================== 遥控器总开关控制 ==============================*/
/**
 * @brief 启用遥控器总开关功能
 * @note  设为1启用，设为0禁用（禁用时代码行为与原来一致）
 *
 * 功能说明：
 * - SWB=1（默认状态）：调试模式，只允许电机调试，不执行发射和换弹流程
 * - SWB=0（手动切换）：正常模式，执行正常的发射和换弹流程
 */
#define ENABLE_RC_MASTER_SWITCH 0

// 遥控器监控任务周期（毫秒）
#define RC_MONITOR_TASK_PERIOD_MS 10

/* ==================== 任务层：事件组位定义 ==================== */

#define EVENT_GIMBAL_READY (1 << 6)      // 0x40 - 云台就绪
#define EVENT_TRIGGER_READY (1 << 2)     // 0x04 - 扳机就绪
#define EVENT_TRIGGER_LOC_READY (1 << 3) // 0x08 - 扳机位置就绪
#define EVENT_ALL_READY 0x4C             // 0x4C - 全部就绪

/* ==================== 业务层：机械结构参数 ==================== */

// 换弹结构相关
#define ConveyorBeltLength 20673
#define SeperationAngle 250
#define PresetLoc (6427.0f)
#define FirstServoLoc (1688.0f)
#define SecondServoLoc (-4658.0f)
#define ThirdServoLoc (-11240.0f)
// 当前单独测试工程标定值：
// Preset = 6427，First = 1688，Second = -4658，Third = -11240

// 储能电机相关
#define LeftStoreLoad (-830.0f)   // 换弹位置
#define RightStoreLoad (830.0f)   // 换弹位置
#define LeftStoreBottom (-930.0f) // 左侧滑台底部
#define RightStoreBottom (930.0f) // 右侧滑台底部
#define LeftStoreTop (0.0f)       // 左侧滑台叉上滑顶部
#define RightStoreTop (0.0f)      // 右侧滑台叉上滑顶部
#define LimitStore 930.0f         // 电机的位置限制
#define StoreSpeed (12.0f)        // 储能电机移动速度

// 扳机射程相关
#define MG996R_store 2500   // 发射扳机待机状态。
#define MG996R_shoot 1000   // 发射扳机发射状态
#define MG996R_initial 2500 // 飞镖支架初始状态，向前摆，方便安装飞镖体
#define MG996R_extend 1750  // 飞镖支架伸出状态
#define MG996R_shrink 900   // 飞镖支架收回状态，向后摆，让SG90的线距离C板短点
#define MG995_initial 2500  // 飞镖支架初始状态，向前摆，方便安装飞镖体
#define MG995_extend 2000   // 飞镖支架伸出状态
#define MG995_shrink 1500   // 飞镖支架收回状态，向后摆，让SG90的线距离C板短点

#define LOAD_TASK_TRAP_VMAX_DEG_S (3500.0f)
#define LOAD_TASK_TRAP_AMAX_DEG_S2 (24000.0f)
#define LOAD_TASK_TRAP_JERK_FACTOR (1.2f)
#define LOAD_TASK_TRAP_DISABLE_JERK 0
#define LOAD_TASK_TRAP_RESET_ON_TARGET_CHANGE 1
#define LOAD_TASK_TRAP_BRAKE_GAIN (0.95f) /* (0,1]，越小越早减速，1.0=理论极限制动 */
#define LOAD_TASK_TRAP_ARRIVE_ZONE (1.0f) /* 到达死区(°)，误差<此值强制锁零速 */
#define LOAD_TASK_TRAP_DECEL_ZONE (40.0f) /* 线性减速区(°)，进入后速度线性压低 */

// 云台转轴相关
// 每发飞镖对应的 YAW(DM4310) 和 Trigger(RM2006) 预设位置
// 索引: [0]=Dart4(第1发), [1]=Dart3(第2发), [2]=Dart2(第3发), [3]=Dart1(第4发)
#define SETUP_YAW_DART4 0.0f
#define SETUP_YAW_DART3 0.0f
#define SETUP_YAW_DART2 0.0f
#define SETUP_YAW_DART1 0.0f

#define SETUP_TRIGGER_DART4 (-100.0f)
#define SETUP_TRIGGER_DART3 (100.0f)
#define SETUP_TRIGGER_DART2 (200.0f)
#define SETUP_TRIGGER_DART1 (0.0f)

// 调试开关：1=跳过“每发前4310/2006到位等待”，直接进入3519流程；0=按原流程等待
#define STORE_BYPASS_SETUP_WAIT 0U

#endif

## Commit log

2025-11-26 项目说明
2025-11-26 C C++ Python等免疫魔法伤害
2025-11-26 上位机代码提交
2025-11-29 调整基础驱动文件
2025-11-29 架构规划
2025-11-29 电机驱动完善
2025-11-29 工程结构优化
2025-11-29 更新文件使用说明
2025-11-29 基础驱动编写
2025-11-29 防止机械结构文件被干掉
2025-11-29 飞镖机械结构文件
    [10_.SLDPRT, 11_.SLDPRT, 12_.SLDPRT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]
2025-11-30 电机初步调试
2025-12-01 基础改进
2025-12-02 基础驱动修改
2025-12-02 相关手册提交
2025-12-02 update:README完善
2025-12-03 fix:大疆电机控制完善
2025-12-03 fix:使用printf可输出信息
2025-12-03 fix:DM电机解算逻辑修复
2025-12-03 update:优化方案（链表+共用体）
2025-12-03 update:更新使用说明
2025-12-05 update:换弹3508单速度环前馈PID调节
2025-12-05 update:任务安排与进度
2025-12-05 update:内环速度环闭环，外环位置环的范围等待测
2025-12-05 fix:CS幻尔，4个驱动板4个协议，真服了，技术也不说清楚
2025-12-05 update:上位机使用教程以及完整展望
2025-12-05 update:更新工程架构
2025-12-05 update:更新工程代码指南
2025-12-05 去除部分多余文件
2025-12-07 fix:提交MDK-ARM工程
2025-12-08 fix:总线舵机控制修复
2025-12-08 fix:修复电机控制
2025-12-08 更新部分配置
2025-12-09 perf:重构结构，进一步完善多电机驱动
2025-12-09 fix:更新电机驱动，修复2006异常
2025-12-09 update：使用说明更新
2025-12-12 update:更新串口通信文件
2025-12-13 update:电机驱动完善
2025-12-13 update:增加一个发射舵机配置
2025-12-13 refactor:重构串口结构，增加usart的module,协议层以及bsp分离
2025-12-13 docs:更新新的UART板级支持包
2025-12-13 fix:2006双环参数测试完成
2025-12-15 update:更新遥控器文件,驱动待编写
2025-12-15 fix:修改部分换弹机构驱动，尝试修复移动漏洞
2025-12-16 fix:换弹功能修复
2025-12-20 update:一些小完善
2025-12-21 perf:换弹任务最终版上线，等待机械重新调整结构
2025-12-21 refactor:虚拟类使用，重构电机调用了流程
2025-12-21 update:J4310电机说明书提交
2025-12-22 update:更新部分基础代码，基础驱动部分完成，等待通信量编写
2026-01-03 fix:解决串口解算数据丢失
2026-01-03 update:更新控制逻辑
2026-01-03 refactor:数据解算和初始化使用虚函数，控制使用API
2026-01-03 docs:更新电机使用文档
2026-01-03 docs:去除部分不必要文档
2026-01-17 fix:串口逻辑简化，通信重布局
2026-01-17 refactor:减少多级指针访问，增加直连API
2026-01-17 update:增加遥控器外设基础
2026-01-17 update:任务重构
2026-01-17 refactor:电机控制重构
2026-01-18 update:修复一些配置问题
2026-01-19 update:更新扳机舵机测试程序，预留一拖三测试线序，预留遥控器
2026-01-19 update:初始化一拖三工程
2026-01-19 update:扳机舵机的调节程序（重装时候确定释放和绷紧数值），新数值为1000和2500
2026-01-19 update:更新为一拖四工程
2026-01-21 refactor:重构电机控制（3508位置环），重构任务结构，增加标志灯
2026-01-21 docs:更新部分使用说明
2026-01-21 update:更新部分任务、模块的单独调试工程
2026-01-22 update:更新遥控器单独测试工程
2026-01-22 update:更新遥控器驱动
2026-01-24 update:更新遥控器可调节单发测试工程
2026-01-29 refactor:遥控器可中断，支持单发调试
2026-02-01 update:测试工程完整更新，CAN收发完善
2026-02-10 update:删除机械结构部分，对换弹测试进行更新
    [06L.stp, 10_.SLDPRT, 11_.SLDPRT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]
2026-02-10 delete:删除机械机构，保留调研文档
    [06L.stp, 10_.SLDPRT, 11_.SLDPRT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]
2026-02-10 update:更新调研文档
2026-02-26 delete:删除部分多余文件
2026-02-26 update:优化部分代码，保证实时性
2026-03-01 update:更新工程结构，重新调一次PID
2026-03-07 refactor:重构换弹任务测试逻辑，使用梯形（可以切换为S形）生成器保证运行丝滑防止脱落
2026-03-07 update:更新电机PID参数、电机算法（S型曲线更新）
2026-03-07 update:使用遥控器调试电机
2026-03-07 update:新的发射和储能PWM舵机参数
2026-03-07 delete:删除错误位置的工程文件
2026-03-07 update:更新电机控制参数和算法
2026-03-11 update:迁入电机死区函数
2026-03-11 update:配置项补全
2026-03-11 update:配置宏增加
2026-03-11 update:更新遥控器控制任务，动态权值
2026-03-11 update:LED通信适当闪烁
2026-03-11 delete:增删部分配置代码
2026-03-11 update:使用待MCU驱动板控制
2026-03-11 fix:修正电机控制PID参数、修正重发逻辑
2026-03-11 refactor:增加单独控制大疆电机的任务以保证电机到位的稳定性、优化整体流程结构
2026-03-12 fix:修复最后状态全部归零

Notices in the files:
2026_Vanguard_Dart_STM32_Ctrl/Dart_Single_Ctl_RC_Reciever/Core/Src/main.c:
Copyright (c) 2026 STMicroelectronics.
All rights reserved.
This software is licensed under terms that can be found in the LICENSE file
